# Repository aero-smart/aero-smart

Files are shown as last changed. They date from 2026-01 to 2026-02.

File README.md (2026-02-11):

# AeroSmart — Desktop-Grade Intelligent Wind Tunnel System

## 1. Project Overview

AeroSmart is a desktop-grade intelligent ducted wind tunnel system designed for aeromodeling enthusiasts and early-stage prototype development teams. The project aims to provide a low-cost, repeatable, and engineering-grade validation tool positioned between CFD (Computational Fluid Dynamics) simulations and real flight testing, assisting in the screening and iterative optimization of design schemes.

The system utilizes a modular wind tunnel structure driven by dual ducted fans, capable of generating stable and controllable high-speed airflow within a small-scale test section. It achieves real-time monitoring of wind speed and airflow states through multi-source sensing methods, including Pitot tubes and acoustic sensors. Combined with PID closed-loop control and automated experimental workflows, users can conduct rapid, comparable testing and evaluation of different shapes or structural designs under consistent aerodynamic conditions. Building on this, the system introduces an AI analysis module that provides targeted suggestions for structural or profile improvements based on aerodynamic performance and experimental data, thereby enhancing design iteration efficiency.

* **Precisely Controllable Airflow Output**
* **Natural Language Intelligent Control**
* **Intelligent Optimization and Improvement Prompts**

---

## 2. Target Users and Use Cases

* **Aeromodeling Enthusiasts & Drone Players:** For validating wing and body simulations when large-scale wind tunnels are inaccessible.
    * AeroSmart provides a stable desktop environment for low-cost aerodynamic testing.
    * Controllable wind speeds allow for comparative analysis.
    * Natural Language Control lowers the barrier to entry, requiring no complex wind tunnel or system control experience.

* **Student Startup Projects:** Bridging the gap between CFD simulation and physical prototyping where a low-cost intermediate validation step is missing.
    * Acts as a workflow validation tool for rapid screening of design options.
    * Multi-source sensor data provides a quantitative basis for decisions.
    * AI analysis and optimization tips improve efficiency.

* **Educational Demonstrations:** CFD results can be abstract; real airflow is vital for teaching.
    * Desktop-sized equipment suitable for classroom environments.
    * Real-time visualization and data overlays turn abstract concepts into intuitive phenomena.
    * Adjustable airflow allows for quick demonstrations of different effects and models.

---

## 3. Technical Solution

### 3.1 Technical Specifications

| Module | Purpose | Specification |
| --- | --- | --- |
| **Intake & Filtering** | Generate straight airflow | 5 mm Aluminum Honeycomb + PLA-CF |
| **Contraction Layer (Nozzle)** | Accelerate airflow | 4:1 Area Ratio |
| **Test Section** | Observation & Data | 5" x 3" x 8"; 5 mm PC Panel |
| **Diffuser & Splitter** | Pressure recovery | Y-splitter with 7° expansion angle |
| **Power Source** | Generate airflow | Dual 70mm EDFs, Max 3.6kg/4.6kg thrust |

### 3.2 Hardware Solution

**3.2.1 Structural Materials**
The overall structure primarily uses 3D printing and laser cutting:

* **Intake Filter Section:** 3003 Aluminum Alloy honeycomb for durability; intake frame 3D printed with PLA-CF.
* **Contraction:** Integrated 3D printing using PETG-CF for structural strength.
* **Test Section:** Laser-cut PC panels; TPU (95A) used for gaskets/seals.
* **Diffuser:** PETG-CF, rigid enough to prevent "flutter" or structural vibration during dual EDF operation.
* **Power Mount:** PETG-CF brackets adapted for 3.6 kg thrust levels.
* **External Skeleton:** M5 threaded rods provide axial tension to keep modules compressed and aligned.

**3.2.2 Flow Field Control**

* **Laminar Core:** The contraction design and aluminum honeycomb create a high-quality laminar core in the center of the test section, reducing background disturbance for stable measurements.
* **Shear Simulation:** By applying different RPM commands to EDF1 and EDF2, the internal Y-splitter maintains two distinct velocity zones, creating a controllable shear layer on the model surface to simulate non-uniform wind gradients.
* **Active Gust Modulation:** The STM32H7 performs high-frequency pulse control on the EDFs to simulate atmospheric turbulence and gust loads, testing the structural resonance of models.
* **Angle Control:** An MG90S servo at the bottom of the test section controls the model’s angle of attack (Optional).

### 3.3 Software Solution (Intelligence & Data Architecture)

**3.3.1 Perception Layer**

* **Airspeed Array (MS4525DO, SDP810):** Measures differential pressure to calculate airspeed via Bernoulli’s principle.
* **Omnidirectional Microphone (ICS-43434):** Collects acoustic data to detect potential turbulence and aerodynamic noise.
* **Camera System:** Uses the SolvePnP algorithm and AprilTags for spatial positioning of the object within the test section.
* **IMU (ICM-42688):** Real-time motion and attitude data collection.
* **Pressure Sensors:** Monitors real-time forces acting on the experimental object.

**3.3.2 Processing Layer**

* **STM32H7:** Handles real-time PID control for thrust stability and Fast Fourier Transform (FFT) on microphone data for acoustic profiling.
* **Raspberry Pi (or Orange Pi):** Runs the MCP Server as an interface for Large Language Models (LLM), enabling natural language queries of sensor data and wind condition commands. It will also host small machine learning models for experimental data analysis.

**3.3.3 Visualization Layer**

* Real-time telemetry displayed via a **Web Dashboard**.
* **"Aero-Current" vectors** overlaid on real-time video of the model.
* **Smoke generator** for immediate visual observation of flow states.

---

## 4. Project Roadmap

| Phase | Core Tasks | Key Deliverables |
| --- | --- | --- |
| **Phase 1: Fluid Prototype** | Printing, honeycomb assembly, single EDF testing. | Stable laminar output (Smoke test). |
| **Phase 2: Perception Fusion** | Integrate Pitot, MIC, IMU, and STM32 PID control. | Real-time airspeed & attitude dashboard. |
| **Phase 3: Smart Interaction** | Raspberry Pi & MCP Server; LLM interface. | Voice/Text control of wind tunnel. |
| **Phase 4: AI Analysis** | Data accumulation; regression model training. | Automated experimental evaluation reports. |

*Target for the current term: Achieve at least Phase 2 and partially complete Phase 3.*

---

## 5. Development and Deployment

### 5.1 Repository Structure

```
aero-smart/
├── firmware/           # STM32H7 embedded Rust firmware (Embassy async runtime)
├── service/            # Backend service (Axum web framework, GraphQL, PostgreSQL)
├── shared/             # Shared Rust library (no_std compatible, cross-platform types)
├── panel/              # Vue.js 3 + Tauri desktop application
├── schematics/         # Electronic circuit schematics
├── model/              # CAD models (STEP format)
└── .github/workflows/  # CI/CD pipelines
```

### 5.2 CI/CD Pipeline

The repository includes automated CI/CD workflows:

#### Build Pipeline for OrangePi Zero 3 (aarch64)

**Workflow:** `.github/workflows/build-aarch64.yml`

This workflow automatically builds the Tauri desktop application for OrangePi Zero 3 (Cortex-A53, aarch64 architecture) with a 1024x600 display when:
- Code is pushed to the `main` branch (panel or shared components)
- Pull requests are created that modify panel or shared code
- Manually triggered via workflow dispatch

**Features:**
- Cross-compilation for aarch64-unknown-linux-gnu target
- Builds .deb packages for easy installation on Debian-based systems
- Artifacts are automatically uploaded and retained for 30 days
- Optimized for OrangePi Zero 3 with fullscreen 1024x600 display

**Build artifacts include:**
- Debian package (.deb) for easy installation
- Build information with commit details and target platform

#### Continuous Integration Pipeline

**Workflow:** `.github/workflows/ci.yml`

Automatically runs checks on code changes:
- Detects which components changed (firmware, service, panel, shared)
- Runs targeted CI tasks for affected components only
- Performs linting, type checking, and builds

### 5.3 Building for OrangePi Zero 3

The panel application is optimized for OrangePi Zero 3 with specific configurations:

**Display Settings:**
- Resolution: 1024x600
- Fullscreen mode enabled
- Window decorations disabled
- Always on top for embedded use

**Build Options:**

1. **Using GitHub Actions (Recommended):**
   - Simply push your code to trigger automatic builds
   - Download artifacts from the Actions tab

2. **Local Build with Docker:**
   ```sh
   ./build_aarch64.sh
   ```

3. **Local Build with npm:**
   ```sh
   cd panel
   pnpm install
   pnpm tauri:build:aarch64
   ```

4. **Using just:**
   ```sh
   just build-panel-aarch64
   ```

For detailed cross-compilation setup instructions, see [panel/README.md](panel/README.md).

### 5.4 Development Workflow

1. **Firmware Development:**
   ```sh
   just build-firmware
   cd firmware && cargo run --release  # Flash to STM32
   ```

2. **Service Development:**
   ```sh
   cargo run -p aerosmart-service
   ```

3. **Panel Development:**
   ```sh
   cd panel
   pnpm install
   pnpm tauri:dev  # Development mode with hot-reload
   ```

For more details, see [CLAUDE.md](CLAUDE.md) for comprehensive development documentation.

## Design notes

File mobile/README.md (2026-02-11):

# mobile

Next Generation Aerodynamic Analysis

## Getting Started

This project is a starting point for a Flutter application.

A few resources to get you started if this is your first Flutter project:

- [Lab: Write your first Flutter app](https://docs.flutter.dev/get-started/codelab)
- [Cookbook: Useful Flutter samples](https://docs.flutter.dev/cookbook)

For help getting started with Flutter development, view the
[online documentation](https://docs.flutter.dev/), which offers tutorials,
samples, guidance on mobile development, and a full API reference.

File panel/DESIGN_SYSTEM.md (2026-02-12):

# AeroSmart Design System

## 1. Introduction

This document outlines the design system for the AeroSmart control panel. The system is built on Tailwind CSS and provides a consistent set of tokens, components, and layout rules to ensure a unified user experience.

## 2. Design Tokens

### Colors

The color palette is semantic and supports theming via CSS variables.

| Token | Variable | Description |
| --- | --- | --- |
| `primary` | `--color-primary` | Main action color (Black) |
| `secondary` | `--color-secondary` | Secondary backgrounds (Light Gray) |
| `accent` | `--color-accent` | Highlight color (Blue) |
| `success` | `--color-success` | Success state (Green) |
| `warning` | `--color-warning` | Warning state (Yellow) |
| `danger` | `--color-danger` | Error/Destructive state (Red) |

### Backgrounds

| Token | Variable | Description |
| --- | --- | --- |
| `bg-page` | `--bg-page` | Main application background |
| `bg-surface` | `--bg-surface` | Card/Panel background |
| `bg-sidebar` | `--bg-sidebar` | Sidebar background |

### Typography

We use the system font stack with Inter as the preferred font.

- **Font Family**: Inter, -apple-system, BlinkMacSystemFont, ...
- **Weights**: Regular (400), Medium (500), Semibold (600), Bold (700)

### Spacing

Based on an 4px grid system.

- `p-1` = 4px
- `p-2` = 8px
- `p-4` = 16px
- `p-6` = 24px

## 3. Components

### Button (`@/components/ui/Button.vue`)

Standard button component with variants.

```vue
<Button variant="primary">Primary Action</Button>
<Button variant="outline">Secondary Action</Button>
<Button variant="ghost" size="icon"><Icon /></Button>
```

### Card (`@/components/ui/Card.vue`)

Content container with consistent styling.

```vue
<Card title="Card Title">
  <p>Content goes here...</p>
</Card>
```

### Badge (`@/components/ui/Badge.vue`)

Status indicator.

```vue
<Badge variant="success" dot>Online</Badge>
```

### Input (`@/components/ui/Input.vue`)

Standard text input.

```vue
<Input v-model="value" label="Username" placeholder="Enter username" />
```

## 4. Layout

### PageLayout (`@/components/layout/PageLayout.vue`)

Standard page structure with header and scrollable content area.

```vue
<PageLayout title="Dashboard">
  <template #actions>
    <Button>Action</Button>
  </template>
  <!-- Content -->
</PageLayout>
```

### Container (`@/components/layout/Container.vue`)

Centers content with max-width and padding.

### Grid (`@/components/layout/Grid.vue`)

Responsive grid layout wrapper.

```vue
<Grid :cols="3">
  <Card>...</Card>
  <Card>...</Card>
  <Card>...</Card>
</Grid>
```

## 5. Iconography

We use **Lucide Vue Next** for icons.

- **Style**: Line style, 2px stroke width.
- **Size**: Default to `16px` (sm), `20px` (md), `24px` (lg).
- **Color**: Use `text-gray-400` for inactive/neutral icons, `text-primary` for active.

## 6. Guidelines

1.  **Use Semantic Colors**: Avoid hardcoded hex values (e.g., use `text-primary` instead of `#1f2937`).
2.  **Use Spacing Scale**: Use Tailwind classes (`p-4`, `m-2`) instead of arbitrary pixels.
3.  **Consistent Cards**: Wrap distinct content sections in `Card` components.
4.  **Responsive First**: Build mobile-first layouts using standard breakpoints (`md`, `lg`).

## 6. Accessibility

- Ensure sufficient color contrast for text.
- Use semantic HTML elements.
- Provide aria-labels for icon-only buttons.

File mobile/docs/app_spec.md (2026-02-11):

# AeroSmart Mobile App Specification

## 1. Overview
This document outlines the specifications for the AeroSmart mobile application, built with Flutter. The app serves as a control and monitoring interface for the AeroSmart wind tunnel system.

**Design Philosophy:**
- **Style:** Minimalist Material Design (Black & White).
- **Focus:** Clarity, performance, and professional engineering aesthetics.

## 2. Core Features

### 2.1 Configuration Management
- Modify all system configuration parameters.
- Real-time adjustment of control parameters (e.g., PID coefficients, if exposed).
- Control actuators:
    - **Throttle:** Dual EDF thrust control (0-100%).
    - **Servo:** Angle of attack adjustment.
- System Commands: Start, Stop, Calibrate, Emergency Stop.

### 2.2 Firmware Update
- Over-the-air (OTA) or wired firmware updates for the STM32H7 microcontroller.
- Progress tracking and verification.

### 2.3 Data Monitoring
- Real-time telemetry visualization.
- **Sensors:**
    - **Airspeed:** Differential pressure & calculated velocity.
    - **IMU:** Acceleration, Gyroscope, Quaternion (Attitude).
    - **Environmental:** Pressure, Temperature, Humidity.
    - **Lidar:** Distance measurements.
    - **Battery:** Voltage and State of Charge (SoC).
    - **Acoustic:** FFT spectrum data (future).

### 2.4 3D Attitude Indicator
- Real-time 3D visualization of the wind tunnel model's orientation based on IMU quaternion data.
- Interactive 3D model viewer.

## 3. Page Structure

### 3.1 Dashboard (Home)
The main landing page providing an immediate system status overview.
- **Header:** Connection status (Bluetooth/WiFi), Battery level.
- **Primary Metrics:** Current Airspeed, Throttle %, Active Mode.
- **3D Widget:** A small, live 3D representation of the model's attitude.
- **Quick Actions:** Emergency Stop, Start/Stop Toggle.

### 3.2 Data Monitor
Detailed view of all sensor streams.
- **Tabbed/Scrollable View:**
    - **Flight Dynamics:** IMU data graphs (Accel/Gyro), Euler angles.
    - **Aerodynamics:** Airspeed, Pitot pressure graphs.
    - **Environment:** Barometer, Lidar distance.
- **Features:** Data logging toggle (future), graph time-scale adjustment.

### 3.3 Controls & Settings
Comprehensive control panel for system parameters.
- **Actuator Control:** Sliders/Inputs for Throttle and Servo Angle.
- **System Config:**
    - PID Tuning parameters (P, I, D for Airspeed/Attitude).
    - Sensor Calibration triggers.
    - Safety limits configuration (Max Throttle, Max Angle).

### 3.4 Firmware
Dedicated page for system maintenance.
- **Current Version:** Display running firmware version.
- **Update:** File picker or cloud fetch for new firmware binaries.
- **Process:** Flash button with progress bar and status log.

## 4. Technical Architecture

### 4.1 Tech Stack
- **Framework:** Flutter (Dart)
- **UI Library:** Material Design 3
- **State Management:** Riverpod
- **Routing:** GoRouter
- **3D Rendering:** `flutter_3d_controller` or `model_viewer_plus`

### 4.2 Project Structure
```
lib/
├── main.dart           # Entry point
├── core/               # Core utilities, theme, constants
│   ├── theme/          # AppTheme (Black & White)
│   └── router/         # GoRouter configuration
├── features/
│   ├── dashboard/      # Dashboard page & widgets
│   ├── monitor/        # Data monitoring page
│   ├── controls/       # Control panel
│   ├── firmware/       # Firmware update logic
│   └── settings/       # App settings
├── shared/             # Shared widgets & models
│   ├── models/         # Data models (ImuData, Config, etc.)
│   └── widgets/        # Reusable UI components
└── services/           # Communication services (Bluetooth/Http - Placeholders for now)
```

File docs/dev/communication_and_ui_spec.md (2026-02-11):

# AeroSmart 上下位机通信协议与前端页面规划文档

本文档详细描述了 AeroSmart 系统中上位机（Panel/Service）与下位机（Firmware）之间的通信协议，WebSocket 接口细节，以及前端各页面的功能期待。

## 1. 通信架构概览

系统采用如下通信链路：
`Firmware (STM32)` <==[Serial (UART)]==> `Service (Tauri Background Task)` <==[WebSocket (JSON)]==> `Frontend (Vue 3)`

*   **下位机 <-> Service**: 使用基于 `rkyv` 的零拷贝二进制协议，为了保证传输稳定，采用了 **Length-Prefixed (4字节长度前缀)** 的分包机制。
*   **Service <-> 前端**: 使用标准 WebSocket 协议，数据格式为 JSON。Service 负责将二进制数据转译为 JSON 广播给前端，并将前端的 JSON 指令转译为二进制发送给下位机。

## 2. 握手协议 (Handshake)

在正式通信前，下位机与 Service 必须完成一次握手以同步状态和时间。

1.  **Service 启动**: 打开串口，进入等待状态。
2.  **下位机发送 Ping**: 发送 `AcknowledgementData` 消息。
3.  **Service 回复 Pong**: 收到合法 Ping 后，Service 获取当前 Unix 时间戳，封装在 `AcknowledgementConfig` 消息中回复。
4.  **连接建立**: 双方进入主循环，开始全双工数据传输。

## 3. WebSocket 接口文档

*   **Endpoint**: `ws://localhost:3000/ws`
*   **数据格式**: JSON
*   **序列化规则**: 遵循 Rust `serde` 的 Enum 外部标签格式，即 `{ "VariantName": { ...fields... } }`。

### 3.1 下行链路 (Downlink): 遥测数据
Service 会将收到的串口数据广播给所有连接的 WebSocket 客户端。

#### 1. IMU 姿态数据 (`ImuData`)
频率: ~20Hz
```json
{
  "ImuData": {
    "accel_z": 9.81,
    "gyro_x": 0.01,
    "gyro_y": -0.02,
    "quad_w": 1.0,
    "quad_i": 0.0,
    "quad_j": 0.0,
    "quad_k": 0.0,
    "time_elapsed_ms": 123456
  }
}
```
*   前端用途: 更新 3D 姿态球或飞机模型。

#### 2. 空速数据 (`PitotAirspeedData`)
频率: ~10Hz
```json
{
  "PitotAirspeedData": {
    "splitter_left": 12.5,
    "splitter_right": 13.0,
    "static_port": 101325.0,
    "time_elapsed_ms": 123456
  }
}
```
*   前端用途: 显示实时空速 (m/s 或 km/h)。

#### 3. 电池状态 (`BatteryData`)
频率: ~1Hz
```json
{
  "BatteryData": {
    "voltage_v": 12.4,
    "soc_percent": 85.0,
    "time_elapsed_ms": 123456
  }
}
```
*   前端用途: 顶部状态栏显示电量和电压图标。

#### 4. 激光雷达测距 (`LidarData`)
频率: ~5Hz
```json
{
  "LidarData": {
    "distance_cm": 150,
    "signal_strength": 100,
    "time_elapsed_ms": 123456
  }
}
```
*   前端用途: 显示对地高度或避障距离。

#### 5. 环境数据 (`BarometerData`)
频率: ~1Hz
```json
{
  "BarometerData": {
    "pressure_pa": 101300.0,
    "temperature_c": 25.5,
    "humidity_percent": 45.0,
    "time_elapsed_ms": 123456
  }
}
```
*   前端用途: 显示环境仪表盘。

#### 6. 声学特征 (`AcousticData`)
频率: ~20Hz
```json
{
  "AcousticData": {
    "overall_spl": 80.5,
    "peak_frequency": 1200.0,
    "peak_magnitude": 0.8,
    "spectral_shape": [0.1, 0.2, ...], // 16 bins
    "turbulence_index": 0.45,
    "time_elapsed_ms": 123456
  }
}
```
*   前端用途: 绘制实时频谱图 (Spectrum Analyzer) 和噪声等级仪表。

#### 7. 振动监测 (`ImuVibrationMetrics`)
频率: ~1Hz
```json
{
  "ImuVibrationMetrics": {
    "accel_z": { "rms_vibration": 0.5, "dominant_frequency_hz": 50.0, "peak_magnitude": 1.2, "time_elapsed_ms": ... },
    "gyro_x": { ... },
    "gyro_y": { ... }
  }
}
```
*   前端用途: 显示机身震动健康度。

### 3.2 上行链路 (Uplink): 控制指令
前端通过 WebSocket 发送 JSON 字符串控制设备。

#### 1. 设置油门/空速 (`ThrottleConfig`)
```json
{
  "ThrottleConfig": {
    "airspeed": 128 // 0-255 映射到 PWM 或 目标速度
  }
}
```

#### 2. 设置舵机角度 (`ServoConfig`)
```json
{
  "ServoConfig": {
    "angle": 90 // 0-180 度
  }
}
```

#### 3. 系统命令 (`Command`)
*   **启动**:
    ```json
    { "Command": "Start" }
    ```
*   **停止**:
    ```json
    { "Command": "Stop" }
    ```
*   **校准**:
    ```json
    { "Command": "Calibrate" }
    ```

#### 4. 传感器配置 (`SensorConfig`)
```json
{
  "SensorConfig": {
    "imu_horizontal": true
  }
}
```

---

## 4. 前端页面功能规划与期待

基于上述数据流，前端应用 (`panel`) 的各页面应包含以下核心功能模块：

### 4.1 仪表盘 (Dashboard)
**定位**: 全局状态监视，核心飞行数据的实时展示。

*   **飞行姿态仪 (PFD)**:
    *   利用 `ImuData` (Quaternions) 渲染 3D 姿态球 (Artificial Horizon)。
    *   显示俯仰角 (Pitch) 和滚转角 (Roll)。
*   **核心指标栏**:
    *   **空速**: 仪表盘样式展示 `PitotAirspeedData`。
    *   **高度/距离**: 数字展示 `LidarData`。
    *   **环境**: 小卡片展示 `BarometerData` (温湿度、气压)。
*   **声学频谱分析**:
    *   使用 ECharts 或 Canvas 绘制 `AcousticData.spectral_shape` 的实时柱状图或折线图。
    *   显示当前 SPL (分贝) 和湍流指数。

### 4.2 控制台 (Control)
**定位**: 主动控制飞机的执行机构和运行状态。

*   **系统状态控制**:
    *   大尺寸按钮组: [启动 (Start)] [停止 (Stop)] [传感器校准 (Calibrate)]。
    *   状态指示灯: 对应下位机反馈的状态（需下位机配合回传状态，目前可通过心跳或特定回传判断）。
*   **油门推杆**:
    *   垂直滑块 (Slider) 控制 `ThrottleConfig`。
    *   实时显示当前设定值 (0-100%)。
*   **舵机测试**:
    *   旋钮或水平滑块控制 `ServoConfig` (0-180°)。
    *   提供“归中 (90°)”快捷按钮。
*   **旋钮编码器反馈**:
    *   显示 `QeiData` 的计数和按键状态，可用于验证物理旋钮输入。

### 4.3 设置 (Settings)
**定位**: 系统级配置与调试信息。

*   **连接配置**:
    *   显示当前连接的串口号、波特率（从 Service 状态获取，或仅做静态展示）。
    *   WebSocket 连接状态指示 (Connected/Disconnected)。
*   **传感器配置**:
    *   开关组件 (Switch) 控制 `SensorConfig.imu_horizontal` (水平/垂直安装校正)。
*   **原始数据监控 (Debug Console)**:
    *   滚动文本框显示收到的原始 JSON 消息流，方便开发调试。
    *   提供“暂停滚动”和“清屏”功能。
*   **阈值报警设置** (前端逻辑):
    *   设置电压低报警阈值。
    *   设置过载 (G-force) 报警阈值。

### 4.4 全局布局 (Layout)
*   **顶部栏 (Status Bar)**:
    *   始终显示: WebSocket 连接状态图标。
    *   始终显示: `BatteryData` (电压/电量)。
    *   始终显示: 系统时间。
*   **侧边栏 (Sidebar)**:
    *   导航菜单: Dashboard / Control / Settings。

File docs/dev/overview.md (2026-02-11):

## AeroSmart — System Overview

AeroSmart is a **desktop-scale intelligent ducted wind tunnel** for aerodynamic testing. It generates controlled airflow (up to 24 m/s) through a 125×75 mm test section using dual 70mm electric ducted fans (EDFs), measures aerodynamic forces via a suite of sensors, and presents real-time data through a web dashboard. The system targets aeromodeling enthusiasts, student engineering teams, and educational demonstrations.

The monorepo contains four major components plus hardware design files:

```
┌──────────────┐    UART/rkyv     ┌──────────────┐   GraphQL/JSON   ┌──────────────┐
│   FIRMWARE   │ ◄──────────────► │   SERVICE    │ ◄──────────────► │    PANEL     │
│  (STM32H7)   │   915200 baud    │  (Axum/PG)   │    HTTP/WS       │  (Vue 3/TS)  │
│ Embassy Rust │                  │  Rust Tokio  │                  │  Vite + Pinia│
└──────────────┘                  └──────────────┘                  └──────────────┘
       │                                │
       │ SPI/I2C/UART/PWM               │ SQLx
       ▼                                ▼
  ┌──────────┐                   ┌──────────────┐
  │ SENSORS  │                   │ PostgreSQL   │
  │ ACTUATORS│                   │  + pgvector  │
  └──────────┘                   └──────────────┘
```

The **shared** crate (`aerosmart-shared`) sits between firmware and service, providing `no_std`-compatible type definitions for all messages and database records.

------

## 1. Firmware (`firmware/`) — Embedded Real-Time Control

The firmware runs on an **STM32H743VG** (ARM Cortex-M7 @ 400 MHz) using the **Embassy async runtime** — a cooperative, interrupt-driven executor purpose-built for embedded Rust.

### 1.1 Initialization (`main.rs`)

On boot, the firmware:

1. **Configures clocks**: PLL1_P → 400 MHz core, 200 MHz AHB, 100 MHz APB
2. **Initializes peripherals**:
   - **SPI1** @ 1 MHz → ICM-42688-P IMU
   - **I2C1** @ 400 kHz → MS4525DO pitot tube + BME280 barometer
   - **I2C3** @ 400 kHz → ADS1115 ADC (analog pressure sensors)
   - **USART1** @ 915200 baud → backend serial link
   - **USART3** @ 115200 baud → TF-Mini S LIDAR
   - **TIM1** @ 600 kHz → DShot ESC protocol for dual EDFs
   - **TIM2** @ 50 Hz → MG90S servo PWM
   - **TIM3** → Quadrature encoder input (QEI)
   - **SPI2** → WS2812B addressable LEDs
   - **SAI1** → I2S stereo microphone @ 44.1 kHz
   - **IWDG** → Independent watchdog (20s timeout)
3. **Spawns concurrent tasks** based on compile-time feature flags (e.g., `airspeed-control`, `fft`, `ahrs`, `imu`, `lidar`, `serial`)

A `TestConfig` struct controls which subsystems are active, allowing selective hardware testing.

### 1.2 Global State (`state.rs`)

All tasks share a single `GlobalState` struct protected by `Mutex<CriticalSectionRawMutex, _>`. It holds:

- **Machine status**: `Idle | Initializing | Running | Error | EmergencyStop`
- **Control mode**: `Manual | Assisted | Autonomous`
- **Sensor readings**: current airspeed, IMU samples, barometer data, battery voltage/SOC, LIDAR distance, analog pressure channels, quaternion attitude, vibration metrics, acoustic FFT data
- **IMU circular buffers**: 1024-sample ring buffers for `accel_z`, `gyro_x`, `gyro_y` (used by FFT task)
- **Setpoints**: desired airspeed, desired servo angle
- **Environmental**: air density (updated from barometer)

Inter-task communication uses **Embassy Signals** (wake-based, single-value) and **Channels** (buffered MPSC queues):

| Signal | Producer | Consumer | Purpose |
| :--- | :--- | :--- | :--- |
| `AIRSPEED_UPDATED_SIGNAL` | Airspeed task | EDF task | Triggers PID recalculation  |
| `IMU_UPDATED_SIGNAL` | IMU task | Serial TX  | New attitude data available |
| `IMU_BUFFER_FULL_SIGNAL`  | IMU task | FFT task | 1024 samples collected |
| `STATUS_UPDATED_SIGNAL` | Various | LED task | Machine state changed |
| `DESIRED_UPDATE_SIGNAL` | Serial RX | Servo task | New angle setpoint |

### 1.3 Sensor Drivers

Each sensor has a low-level driver (register definitions) and a high-level interface:

**ICM-42688-P IMU** (`sensors/imu_spi.rs`, `drivers/icm_42688_p.rs`):

- 6-DOF: ±16g accelerometer + ±2000 dps gyroscope
- SPI register access with configurable full-scale range and output data rate
- Event-driven at ~1 kHz via GPIO interrupt (data-ready pin)

**MS4525DO Pitot Tube** (`sensors/pitot_i2c.rs`):

- Differential pressure sensor at I2C address 0x28
- 14-bit raw pressure → ±1 PSI (±6894 Pa)
- 11-bit temperature: `(raw × 200/2047) − 50`
- Polled at 100 Hz
- Kalman filter implemented

**BME280 Barometer** (`drivers/bme_280.rs`):

- Pressure, temperature, humidity at I2C address 0x76
- 4× oversampling, normal mode
- Polled at 10 Hz (decimated from the 100 Hz pitot loop)
- Used to compute real-time air density via the Magnus formula

**ADS1115 ADC** (`sensors/adc_i2c.rs`, `drivers/ads1115.rs`):

- 16-bit, 4-channel ADC at I2C address 0x48
- Reads analog pressure transducers (XGZP6847A) and battery voltage
- Single-shot conversion triggered with data-ready interrupt

**TF-Mini S LIDAR** (`sensors/lidar_uart.rs`):

- 9-byte UART frames (header `0x59 0x59`, distance_cm, signal_strength)
- Polled every 3 seconds
- **Safety**: triggers `EmergencyStop` if distance < 30 cm

**ICS-43434 Microphone** (`audio_i2s.rs`):

- I2S stereo, 24-bit, 44.1 kHz via SAI1
- 4096-sample buffer for acoustic FFT

### 1.4 Algorithms

**PID Airspeed Controller** (`algorithms/airspeed.rs`):

The controller uses a **feedforward + feedback** architecture with three operating states:

| State | Condition | Strategy |
| :--- | :--- | :--- |
| **Reaching** | error > 20% | Pure feedforward from mass conservation model |
| **Approaching** | 5% < error ≤ 20% | Sigmoid-weighted blend of feedforward + PID |
| **Cruising** | error ≤ 5% | Full PID feedback control |

The feedforward model derives throttle from physics:
$$
v_{\mathrm{edf}} = \sqrt{\dfrac{F_\mathrm{thrust}}{\rho \cdot A_{\mathrm{edf}}}}\\
\mathrm{throttle} = \dfrac{v_{\mathrm{desired}}}{v_\max}
$$
Voltage compensation scales for battery sag. PID gains: $K_p=1.0, K_i=0.1, K_d=0.05$, output clamped to ±50.

**Madgwick AHRS** (`algorithms/madgwick.rs`):

- Fuses accelerometer + gyroscope into a quaternion ($w, i, j, k$)
- Sample rate: 1000 Hz, beta: 0.033
- Outputs Euler angles (roll, pitch, yaw) for telemetry

**Kalman Airspeed Filter** (`algorithms/airspeed_filter.rs`):

- Single-state Kalman filter for smoothing pitot readings
- Process variance $Q=0.001$, measurement variance R=0.1

**Motion FFT** (`algorithms/motion_fft.rs`):

- 1024-point real FFT on IMU circular buffer using `microfft`
- Hann windowing (generated at compile time by `build.rs`)
- Extracts: RMS vibration, dominant frequency, peak magnitude

**Acoustic FFT** (`algorithms/acoustic_fft.rs`):

- 4096-point real FFT on microphone data
- Blackman-Harris windowing (better sidelobe suppression)
- Extracts: overall SPL, peak frequency, 16-band spectral shape, turbulence index (spectral flux)

### 1.5 Concurrent Tasks

All tasks run as Embassy async functions on the Cortex-M7:

| Task | Rate | Key Logic |
| :--- | :--- | :--- |
| **Airspeed** | 100 Hz | Reads pitot, computes airspeed from Bernoulli `v=√(2ΔP/ρ)`, updates state |
| **IMU** | 1 kHz | Reads IMU via SPI, runs Madgwick AHRS, fills FFT buffer |
| **EDF** | event-driven | Waits for `AIRSPEED_UPDATED_SIGNAL`, runs PID, sends DShot to both EDFs |
| **Servo** | event-driven | Waits for `DESIRED_UPDATE_SIGNAL`, sets PWM duty cycle |
| **IMU FFT** | event-driven | Waits for `IMU_BUFFER_FULL_SIGNAL`, computes vibration metrics |
| **LIDAR** | 0.33 Hz | Measures distance, triggers emergency stop on proximity |
| **Battery** | 1 Hz | Reads ADC, computes voltage and SOC from lookup table |
| **Analog Pressure** | 20 Hz | Polls ADS1115 across 4 channels |
| **LED** | event-driven | Maps machine status to WS2812B color |
| **Watchdog** | 1 Hz | Pets the independent watchdog |
| **Acoustic Sample** | continuous | Streams I2S audio, buffers 4096 samples |
| **Acoustic Analysis** | event-driven | FFT on audio, extracts spectral features |
| **Serial RX** | continuous | Deserializes rkyv commands from service |
| **Serial TX** | 100 Hz base  | Transmits telemetry at tiered rates (IMU@20Hz, airspeed@10Hz, LIDAR@5Hz, battery@1Hz) |
| **QEI** | 20 Hz | Reads encoder position and button state |

### 1.6 Actuator Control

**Dual EDFs** (`executors/edf.rs`): Controlled via DShot digital protocol over TIM1 PWM at 600 kHz. Throttle range 0–2000. Both fans receive symmetric commands.

**Servo** (`executors/servo.rs`): Standard 50 Hz PWM on TIM2. Pulse width maps linearly: 1.0 ms (0°) to 2.0 ms (180°).

### 1.7 Utility Modules

- **`utils/pitot.rs`**: Bernoulli equation $v=\sqrt{\dfrac{2\cdot\Delta P}{\rho}}$
- **`utils/mass_conservation.rs`**: Feedforward throttle from thrust equation and continuity
- **`utils/magnus.rs`**: Moist air density from Magnus saturation vapor pressure formula
- **`utils/battery.rs`**: VREFINT-calibrated ADC conversion, 21-point SOC lookup table for 4S LiPo
- **`utils/pressure_adc.rs`**: Analog pressure transducer voltage-to-Pa conversion

------

## 2. Shared Library (`shared/`) — Cross-Platform Types

The `aerosmart-shared` crate is `#![no_std]`-compatible with feature gates:

| Feature | What it enables |
| :--- | :--- |
| `std` (default) | Standard library, rkyv std, chrono std |
| `sql` | SQLx `FromRow`, pgvector, UUID types |
| `serde` | JSON serialization for web API |
| `defmt` | Embedded logging format |
| `graphql` | Juniper GraphQL derives |
| `proto` | Protobuf via prost |

### 2.1 Serial Protocol (`serial.rs`)

Defines all messages exchanged over UART:

**Service → Firmware (Commands)**:

- `ThrottleConfig { airspeed: u8 }` — target airspeed percentage
- `ServoConfig { angle: u8 }` — angle of attack
- `SensorConfig { imu_horizontal: bool }` — IMU orientation
- `Command { Start | Stop | Calibrate }` — state machine control
- `AcknowledgementConfig { ack: bool, unix_timestamp_ms: u64 }`

**Firmware → Service (Telemetry)**:

- `ImuData` — accel_z, gyro_x/y, quaternion (w/i/j/k), timestamp
- `PitotAirspeedData` — splitter_left/right, static_port, timestamp
- `AcousticData` — SPL, peak_frequency, peak_magnitude, 16-band spectral_shape, turbulence_index
- `ImuVibrationMetrics` — RMS, dominant_frequency, peak_magnitude (×3 axes)
- `BarometerData` — pressure, temperature, humidity
- `BatteryData` — voltage, SOC percentage
- `LidarData` — distance_cm, signal_strength
- `AnalogPressureSensorData` — 4 channels + validity bitmask
- `QeiData` — encoder position, direction, button state

All types are wrapped in a `SerialMessage` enum. Serialized with **rkyv** for zero-copy decoding — the firmware can interpret messages in-place without allocation.

### 2.2 Database Records (`sql.rs`)

Conversion methods (`to_record(session_uuid)`) transform telemetry structs into SQL-ready records:

- `ImuRecord` — includes full quaternion, references experiment session UUID
- `PitotAirspeedRecord` — three pressure channels per session
- `AcousticRecord` — SPL + spectral_shape stored as `pgvector::Vector` for ML similarity queries
- `Experiment` — session metadata (name, description, UUID)

------

## 3. Backend Service (`service/`) — Web API & Persistence

The service is built on **Axum** (web framework), **Juniper** (GraphQL), **SQLx** (PostgreSQL), and **tokio-serial** (UART).

**Current status**: The service is in **skeleton phase** — dependencies are configured, the database migration is written, and the serial wrapper exists, but the Axum server, GraphQL schema, and database query layer are not yet implemented.

### 3.1 Database Schema (`migrations/20260111031124_initial.sql`)

```sql
-- Extensions
CREATE EXTENSION IF NOT EXISTS vector;       -- pgvector for embeddings
CREATE EXTENSION IF NOT EXISTS "uuid-ossp";  -- UUID generation

-- Tables
experiments         (id UUID PK, name, description, created_at, updated_at)
imu_records         (id SERIAL PK, session FK, timestamp, accel/gyro/quaternion fields)
pitot_airspeed_records (id SERIAL PK, session FK, timestamp, 3 pressure channels)
acoustic_records    (id SERIAL PK, session FK, timestamp, SPL, peak_freq,
                     spectral_shape vector(32), turbulence_index)
```

Indexes cover session+timestamp lookups (descending) and an HNSW vector cosine similarity index on `acoustic_records.spectral_shape` for nearest-neighbor queries.

### 3.2 Serial Communication (`serial/mod.rs`)

A thin wrapper around `tokio_serial::SerialPort` with raw `read()`/`write()` methods. The intended flow:

1. Service opens UART port at 915200 baud
2. Incoming bytes are deserialized via rkyv into `SerialMessage` variants
3. Telemetry data is persisted to PostgreSQL and broadcast to frontend
4. Commands from frontend are serialized and sent to firmware

### 3.3 Planned Architecture

Based on dependencies and the shared library:

- **Axum routes**: REST + GraphQL endpoint (`/graphql`)
- **Juniper resolvers**: queries for experiments, sensor data; mutations for experiment management and control commands
- **SQLx pool**: connection pooling with type-safe queries
- **Context/DI**: `AppState` holding DB pool, serial handle, and schema

------

## 4. Frontend Panel (`panel/`) — Vue 3 Dashboard

A **Vue 3 + TypeScript + Vite** application using Pinia for state management.

**Current status**: Clean boilerplate — the toolchain is fully configured but no application features are implemented yet.

### 4.1 Toolchain

| Tool | Version | Purpose |
| :--- | :--- | :--- |
| Vite | 8.0.0-beta.7 | Build tool + HMR dev server |
| Vue | 3.5.26 | UI framework (Composition API) |
| Pinia | 3.0.4 | State management |
| Vue Router | 4.6.4 | Client-side routing |
| TypeScript | 5.9.3 | Type safety |
| vue-tsc | 3.2.2 | Vue template type checking |
| Vitest | 4.0.16 | Unit testing |
| Playwright | 1.57.0 | E2E testing (Chromium, Firefox, WebKit) |
| ESLint + Oxlint | 9.39.2 / 1.38.0 | Linting |
| Prettier | 3.7.4 | Formatting (no semicolons, single quotes) |

### 4.2 Application Bootstrap

```
index.html → src/main.ts → createApp(App)
  → app.use(createPinia())    // State management
  → app.use(router)           // Routing
  → app.mount('#app')         // DOM mount
```

The router has no routes defined yet. A single example Pinia store (`counter.ts`) demonstrates the Composition API pattern.

------

## 5. End-to-End Data Flow

Here's how a complete airspeed control loop works:

```
1. USER sets target airspeed in Vue dashboard
2. PANEL sends GraphQL mutation to SERVICE
3. SERVICE serializes ThrottleConfig via rkyv, writes to UART
4. FIRMWARE Serial RX task deserializes command, updates desired_airspeed in GlobalState
5. FIRMWARE Airspeed task reads MS4525DO pitot tube at 100 Hz
   → Bernoulli: v = √(2ΔP/ρ)
   → ρ updated from BME280 every 10 cycles
   → Kalman filter smooths measurement
   → Fires AIRSPEED_UPDATED_SIGNAL
6. FIRMWARE EDF task wakes, reads current vs desired airspeed
   → PID controller computes throttle (feedforward + feedback)
   → Sends DShot command to both EDFs via TIM1
7. FIRMWARE Serial TX sends PitotAirspeedData @ 10 Hz over UART
8. SERVICE deserializes telemetry, stores in PostgreSQL, pushes to frontend
9. PANEL updates dashboard in real-time
```

Safety runs in parallel:

- Watchdog task pets IWDG every 1s (20s timeout → hardware reset on hang)
- LIDAR checks proximity every 3s → `EmergencyStop` if < 30 cm
- Battery task monitors voltage → warnings on low SOC

------

## 6. Build System

**Firmware**: Rust 1.90, target `thumbv7em-none-eabi`, flashed via `probe-rs`. The `build.rs` generates FFT window coefficients (Hann 1024-point, Blackman-Harris 1024-point) at compile time. Both dev and release profiles use LTO and size optimization (`opt-level = "z"`).

**Service**: Standard Rust with Tokio async runtime. Database migrations via SQLx.

**Frontend**: pnpm + Vite. `pnpm build` runs `vue-tsc --build` (type check) then Vite production build in parallel.

**Workspace**: Cargo workspace with resolver v2, three members (`firmware`, `service`, `shared`). Panel is outside the Cargo workspace (Node.js project).

------

## 7. Project Status

The project is in **Phase 2 (Perception Fusion)**:

| Component | Status |
| :--- | :--- |
| Firmware | **Substantially complete** — all sensor drivers, algorithms, tasks, and actuator control are implemented |
| Shared library  | **Complete** — all message types, database records, and serialization are defined with tests |
| Backend service | **Skeleton** — dependencies configured, migration written, serial wrapper exists, but no server logic |
| Frontend | **Boilerplate** — toolchain configured, no application features |
| Hardware design | **In progress** — KiCAD schematics and CAD models for EDF/ESC present |

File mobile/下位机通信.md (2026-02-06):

# 🛰️ AeroSmart 下位机通信指南 (V1.2)

本指南详细说明了 AeroSmart 项目中 **上位机服务 (Service)** 与 **下位机固件 (Firmware)** 之间，以及固件与底层传感器/执行器之间的通信机制。

---

## 1. 通信架构概览

AeroSmart 采用端到端的 Rust 协议栈，通过 **Monorepo** 结构确保协议在不同层级间的高度一致性。

*   **上位机 (Service)**: 运行于 PC/服务器，负责高层控制、数据记录与可视化。
*   **下位机 (Firmware)**: 运行于 STM32H7，负责实时控制、传感器采集与硬件抽象。
*   **共享层 (Shared)**: 定义了跨端通用的消息格式、序列化方案及数据库映射 (Scopes)。

---

## 2. 上位机 ↔ 下位机通信协议 (主协议)

### 2.1 物理层配置
*   **接口**: UART (USART1)
*   **波特率**: **915200 bps**
*   **引脚**: PA9 (TX), PA10 (RX)
*   **流控**: 无 (None)

### 2.2 握手与同步流程 (Handshake)

系统启动时必须进行一次握手，以同步时间并确认连接建立。此过程在固件 `main` 函数初始化阶段阻塞执行。

1.  **Ping (Firmware -> Service)**:
    *   固件初始化串口后，立即发送一个 `AcknowledgementData` 消息。
    *   Payload: `time_elapsed_ms` (系统启动后的毫秒数)。
2.  **Pong & Sync (Service -> Firmware)**:
    *   上位机收到 Ping 后，需回复一个 `AcknowledgementConfig` 消息。
    *   Payload: `ack = true`, `unix_timestamp_ms` (当前 UNIX 时间戳)。
3.  **Ready**:
    *   固件收到回复后，利用 `unix_timestamp_ms` 校准内部 RTC 时钟，随后启动所有异步任务 (UART RX/TX, Sensors, Control Loop)。

### 2.3 序列化方案
*   **框架**: **rkyv** (Zero-copy deserialization)。
*   **对齐**: 消息直接序列化为字节流传输，未显式使用 COBS/SLIP 封包。依赖底层传输可靠性。

---

## 3. 数据结构设计与 Scopes

所有通信消息封装在 `SerialMessage` 枚举中。数据结构设计不仅服务于通信，还通过 Feature Flags (如 `sql`) 定义了持久化 Scope。

### 3.1 控制指令 (Service -> Firmware)

| 消息类型 (Scope: Control) | 结构体 | 关键字段 | 说明 |
| :--- | :--- | :--- | :--- |
| **Command** | `Command` (Enum) | `Start`, `Stop`, `Calibrate` | **Start**: 进入 Running 状态<br>**Stop**: 进入 Idle 状态<br>**Calibrate**: 进入 Initializing 状态 |
| **ThrottleConfig** | `ThrottleConfig` | `airspeed` (u8) | 设定目标风速 (0-255 映射) |
| **ServoConfig** | `ServoConfig` | `angle` (u8) | 设定舵机角度 (0-255 映射) |
| **SensorConfig** | `SensorConfig` | `imu_horizontal` (bool) | 传感器安装方向配置 |
| **AcknowledgementConfig** | `AcknowledgementConfig` | `ack` (bool), `unix_timestamp_ms` (u64) | 握手与时间同步专用 |

### 3.2 遥测数据 (Firmware -> Service)

此类数据通常实现了 `to_record` 方法，支持直接映射为 SQL 数据库记录 (Scope: Persistence)。

#### 3.2.1 高频实时数据

| 消息类型 | 频率 | 结构体定义 | 数据库 Scope (Table) |
| :--- | :--- | :--- | :--- |
| **ImuData** | 20 Hz | `accel_z`, `gyro_x/y` (f32)<br>`quad_w/i/j/k` (f32, 四元数) | `imu_records` |
| **AcousticData** | 20 Hz | `overall_spl` (f32, 声压级)<br>`peak_frequency` (f32)<br>`spectral_shape` ([f32; 16], 频谱) | `acoustic_records` |
| **PitotAirspeedData** | 10 Hz | `splitter_left/right` (f32)<br>`static_port` (f32) | `pitot_records` |
| **AnalogPressureSensorData** | 10 Hz | `pressures_pa` ([f32; 4])<br>`valid_bitmask` (u8) | (待定) |

#### 3.2.2 低频监控数据

| 消息类型 | 频率 | 结构体定义 | 说明 |
| :--- | :--- | :--- | :--- |
| **LidarData** | 5 Hz | `distance_cm` (u16)<br>`signal_strength` (u16) | 激光雷达测距 |
| **ImuVibrationMetrics** | 1 Hz | `accel_z`, `gyro_x/y` (RMS, Peak, Freq) | 振动特征分析 |
| **BarometerData** | 1 Hz | `pressure_pa`, `temperature_c`, `humidity_percent` | 环境气象状态 |
| **BatteryData** | 1 Hz | `voltage_v` (f32)<br>`soc_percent` (f32) | 电源管理系统状态 |
| **QeiData** | Event | `position_counts` (u16)<br>`direction` (bool) | 旋钮/编码器交互 |
| **AcknowledgementData** | Once | `time_elapsed_ms` (u64) | 仅用于握手 Ping |

---

## 4. 固件 ↔ 传感器/执行器通信 (内部协议)

下位机通过硬件接口与外设交互，这些协议对上位机透明，但决定了数据的来源与精度。

### 4.1 激光雷达 (LiDAR)
*   **接口**: UART3 (PC10/PC11), 115200 bps
*   **协议**: TFmini-S 9字节定长帧 (`0x59 0x59 ...`)
*   **驱动**: `firmware/src/sensors/lidar_uart.rs`

### 4.2 空速与环境 (Pitot & Env)
*   **接口**: I2C1 (PB8/PB9), 400 kHz
*   **设备**:
    *   **MS4525DO**: 空速管差压传感器 (Addr: `0x28`)
    *   **BME280**: 温湿度气压传感器 (Addr: `0x76`/`0x77`)
*   **驱动**: `firmware/src/sensors/pitot_i2c.rs`

### 4.3 模拟气压阵列 (Analog Pressure)
*   **接口**: I2C3 (PA8/PC9), 400 kHz -> ADS1115 ADC
*   **设备**: XGZP6847A 等模拟输出传感器
*   **驱动**: `firmware/src/sensors/adc_i2c.rs`

### 4.4 惯性测量单元 (IMU)
*   **接口**: SPI1 (PB3/PB4/PB5), 1 MHz
*   **设备**: ICM-42688-P (6-Axis)
*   **驱动**: `firmware/src/sensors/imu_spi.rs`

### 4.5 动力系统 (EDF & Servo)
*   **EDF 风机**: TIM1 (PE9/PE11), **DShot600** 数字协议 (600 kHz)
*   **舵机**: TIM2 (PA0), 50 Hz PWM
*   **驱动**: `firmware/src/executors/edf.rs`, `servo.rs`

---

## 5. 调试与日志 (RTT)

*   **机制**: SEGGER RTT (Real Time Transfer)
*   **工具**: `defmt` (Logging) + `probe-rs` (Host side)
*   **用途**: 固件不占用 UART1 进行 `printf` 调试，确保通信带宽完全用于协议数据。

---

## 6. 开发注意事项

1.  **握手超时**: 上位机应在打开串口后立即监听 `AcknowledgementData`。若固件已启动，可能需发送 Reset 指令或设计重连机制（当前固件仅在启动时握手）。
2.  **数据对齐**: 由于未实现帧头同步，建议上位机在解析失败时清空缓冲区并重新尝试同步。
3.  **状态机**: 上位机需维护与固件一致的状态机 (`Idle` -> `Initializing` -> `Running`)，部分数据（如控制回路反馈）仅在 `Running` 状态下有效。

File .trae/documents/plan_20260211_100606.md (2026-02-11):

我已经完成了所有修复和国际化工作。

### 主要改动
1.  **修复遗漏的翻译**:
    -   在 `DashboardView.vue` 中找到了用户指出的 "Wind Input", "Pressure Difference Monitor" 以及其他遗漏的硬编码字符串（如 "Wind Speed Display", "Wind Direction" 等），并全部替换为 `$t(...)` 调用。
2.  **修复代码逻辑**:
    -   检查并修复了 `PowerView.vue` 中的一个 Bug：在 `watch` 函数中访问 `availableSources` 时缺少了 `.value`，这会导致运行时错误。
    -   确认 `ControlView.vue` 的代码逻辑正确，所有 `computed` 属性的使用都正确带上了 `.value`。
3.  **完善设置页面**:
    -   更新了 `SettingsModal.vue`，将硬编码的 `alert` 和 `confirm` 消息替换为国际化字符串。
4.  **验证**:
    -   使用 `grep` 搜索确认了所有关键的硬编码英文字符串（如 "Wind Input"）现在只存在于注释和翻译文件中，视图代码中已清除干净。

### 系统概览
-   **语言**: 支持 英文 (默认) 和 中文。
-   **状态管理**: 使用 Pinia 持久化存储用户语言偏好。
-   **响应式**: 所有图表配置、传感器列表和建议内容现在都是响应式的，切换语言时会立即更新，无需刷新页面。

现在您可以启动开发服务器并测试语言切换功能。所有界面元素，包括图表标题和动态生成的列表，都应该能正确显示中文。

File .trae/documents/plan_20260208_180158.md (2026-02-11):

# Frontend WebSocket Implementation Plan

## 1. WebSocket API Documentation

### Connection Details

* **URL**: `ws://localhost:3000/ws`

* **Protocol**: JSON over WebSocket

* **Serialization**: Rust `serde` Enum (External Tagging) -> `{"Variant": { ...fields... }}`

### Downlink (Server -> Client)

The server broadcasts telemetry data as JSON objects. The keys correspond to `SerialMessage` variants.

| Message Variant | JSON Structure Example | Target Store State |
| :--- | :--- | :--- |
| **ImuData** | `{"ImuData": {"accel_z": 9.8, "gyro_x": 0.1, "gyro_y": 0.1, "quad_w": 1.0, "quad_i": 0.0, "quad_j": 0.0, "quad_k": 0.0, "time_elapsed_ms": 1000}}` | `imu` (Need Quat->Euler conv) |
| **PitotAirspeedData** | `{"PitotAirspeedData": {"splitter_left": 12.0, "splitter_right": 12.0, "static_port": 1013.0, "time_elapsed_ms": 1000}}` | `airspeed` (Calculate velocity if needed or use raw) |
| **BatteryData** | `{"BatteryData": {"voltage_v": 12.6, "soc_percent": 95.0, "time_elapsed_ms": 1000}}` | `battery` |
| **LidarData** | `{"LidarData": {"distance_cm": 150, "signal_strength": 100, "time_elapsed_ms": 1000}}` | `lidar` |
| **BarometerData** | `{"BarometerData": {"pressure_pa": 101325, "temperature_c": 25.0, "humidity_percent": 50.0, "time_elapsed_ms": 1000}}` | `env` |
| **AcousticData** | `{"AcousticData": {"overall_spl": 80.0, "peak_frequency": 1000, "spectral_shape": [...], "turbulence_index": 0.5, "time_elapsed_ms": 1000}}` | `acoustic` |
| **AcknowledgementData** | `{"AcknowledgementData": {"time_elapsed_ms": 1000}}` | Connection Heartbeat |

### Uplink (Client -> Server)

The client sends control commands as JSON objects.

| Action | JSON Payload |
| :--- | :--- |
| **Set Throttle** | `{"ThrottleConfig": {"airspeed": <0-255>}}` |
| **Set Servo** | `{"ServoConfig": {"angle": <0-180>}}` |
| **Start System** | `{"Command": "Start"}` |
| **Stop System**  | `{"Command": "Stop"}` |
| **Calibrate** | `{"Command": "Calibrate"}` |

***

## 2. Implementation Steps

### Step 1: Update `panel/src/stores/device.ts`

* **Add WebSocket State**: `socket: WebSocket | null`, `reconnectTimer: any`.

* **Implement** **`connect()`** **action**:

  * Initialize `WebSocket`.

  * Bind `onopen` -> `isConnected = true`.

  * Bind `onclose`/`onerror` -> `isConnected = false`, trigger reconnection (3s delay).

  * Bind `onmessage` -> Parse JSON, dispatch to `handleMessage()`.

* **Implement** **`handleMessage(payload)`**:

  * Switch on object keys (`ImuData`, `BatteryData`, etc.).

  * Update reactive refs (`imu`, `battery`, `env`, etc.).

  * **Math Helper**: Implement `quaternionToEuler(w, x, y, z)` to update `imu.attitude` (Roll/Pitch/Yaw) for the UI.

* **Implement Control Actions**:

  * `setThrottle(val)`: `socket.send(JSON.stringify({"ThrottleConfig": {"airspeed": val}}))`

  * `setServo(val)`: `socket.send(JSON.stringify({"ServoConfig": {"angle": val}}))`

  * `sendCommand(cmd)`: `socket.send(JSON.stringify({"Command": cmd}))`

### Step 2: Integrate in `App.vue`

* Call `deviceStore.connect()` on mount to initiate the connection lifecycle.

### Step 3: Verify Data Mapping

* Ensure `PitotAirspeedData` mapping logic handles the raw pressure vs calculated airspeed (Note: Firmware `ThrottleConfig` uses `airspeed` field for throttle value, likely mapping 0-255. `PitotAirspeedData` returns raw sensor values).

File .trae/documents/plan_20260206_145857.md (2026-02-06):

# Service Implementation Plan: Serial Bridge & WebSocket

## 1. Project Structure & Dependencies
*   **Dependencies**: Ensure `service/Cargo.toml` includes `axum` (WebSocket support), `tokio` (runtime, sync), `tokio-serial` (serial port), `rkyv` (deserialization), `serde` & `serde_json` (JSON serialization for frontend), and `tracing` (logging).
*   **Architecture**:
    *   **Main Task**: Sets up channels, spawns the serial task, and runs the Axum server.
    *   **Serial Task**: Handles the physical layer (UART), handshake, and binary protocol (Rkyv).
    *   **Axum Handler**: Manages WebSocket connections, broadcasting telemetry, and forwarding commands.

## 2. Serial Communication Logic (Phase 1)
*   **Handshake**:
    *   Open the serial port (path via CLI arg, e.g., `/dev/tty.usbmodem...`).
    *   **Loop**: Read bytes looking for `SerialMessage::AcknowledgementData` (Ping).
    *   **Action**: Upon receipt, immediately send `SerialMessage::AcknowledgementConfig` (Pong) with the current Unix timestamp (`SystemTime`).
    *   **Transition**: Once handshaken, enter the main data loop.
*   **Main Loop (Uplink/Downlink)**:
    *   **Reading**: Read bytes from UART -> Deserialize `ArchivedSerialMessage` (Rkyv) -> Deserialize to Native Type -> Serialize to JSON -> Broadcast to WebSockets.
    *   **Writing**: Receive JSON command from WebSocket channel -> Deserialize to `SerialMessage` -> Serialize to Rkyv bytes -> Write to UART.

## 3. WebSocket Integration (Phase 2)
*   **Endpoint**: `GET /ws`
*   **Protocol**:
    *   **Server -> Client**: JSON string of telemetry data (e.g., `{"ImuData": {...}}`).
    *   **Client -> Server**: JSON string of control commands (e.g., `{"ThrottleConfig": {"airspeed": 100}}`).
*   **Concurrency**: Use `tokio::sync::broadcast` for fan-out telemetry and `tokio::sync::mpsc` for fan-in commands.

## 4. Implementation Details
*   **Error Handling**: No mocks. If serial fails to open or Rkyv fails to deserialize (after handshake), log error or panic as appropriate for a critical failure.
*   **Data Flow**:
    *   `Firmware` --(UART/Rkyv)--> `Serial Task` --(JSON)--> `Broadcast Channel` --(WS)--> `Frontend`
    *   `Frontend` --(WS/JSON)--> `Axum Handler` --(MPSC Channel)--> `Serial Task` --(UART/Rkyv)--> `Firmware`

## 5. Next Steps
*   Update `service/src/main.rs` with the full implementation.
*   The code will include the complete `SerialMessage` enum handling to ensure all defined types in `shared` are covered.

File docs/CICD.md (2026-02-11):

# CI/CD Pipeline for AeroSmart Panel

## Overview

This document describes the automated CI/CD pipeline for building the AeroSmart Panel Tauri application for OrangePi Zero 3 (aarch64).

## Architecture

```
┌─────────────────────────────────────────────────────────────┐
│                    GitHub Repository                         │
│                  aero-smart/aero-smart                       │
└────────────┬────────────────────────────────────────────────┘
             │
             │ Push to main / PR
             │ (panel/** or shared/** changes)
             │
             ▼
┌─────────────────────────────────────────────────────────────┐
│           GitHub Actions Workflow                            │
│         .github/workflows/build-aarch64.yml                  │
└────────────┬────────────────────────────────────────────────┘
             │
             ├─► Setup Environment
             │   ├── Rust toolchain (stable)
             │   ├── Node.js 24
             │   ├── pnpm 10.20.0
             │   └── Add aarch64-unknown-linux-gnu target
             │
             ├─► Install Cross-Compilation Dependencies
             │   ├── Add arm64 architecture to dpkg
             │   ├── Install aarch64 GCC/G++ toolchain
             │   ├── Install arm64 system libraries:
             │   │   ├── libwebkit2gtk-4.1-dev:arm64
             │   │   ├── libgtk-3-dev:arm64
             │   │   ├── libayatana-appindicator3-dev:arm64
             │   │   ├── librsvg2-dev:arm64
             │   │   ├── libssl-dev:arm64
             │   │   ├── libasound2-dev:arm64
             │   │   └── libdbus-1-dev:arm64
             │   └── Configure Cargo linker
             │
             ├─► Build Application
             │   ├── Install frontend dependencies (pnpm)
             │   ├── Build Tauri app for aarch64-unknown-linux-gnu
             │   └── Generate .deb package
             │
             └─► Upload Artifacts
                 ├── Debian package (.deb)
                 ├── AppImage (if generated)
                 └── BUILD_INFO.txt
                      ├── Branch name
                      ├── Commit SHA
                      ├── Build date
                      └── Target platform info
```

## Target Platform

**Hardware:** OrangePi Zero 3
- **CPU:** Allwinner H618 (4x Cortex-A53, 64-bit)
- **Architecture:** aarch64 (ARM64)
- **Display:** 1024x600 pixels

**Software Stack:**
- **OS:** Linux-based (Debian/Ubuntu compatible)
- **Runtime:** Tauri 2.x (WebView2 + Rust backend)
- **Display Mode:** Fullscreen, no decorations

## Build Triggers

The workflow is triggered automatically by:

1. **Push to main branch**
   - Only when files in `panel/**` or `shared/**` are modified
   - Or when the workflow file itself is modified

2. **Pull Requests**
   - Targeting the main branch
   - Affecting `panel/**` or `shared/**`

3. **Manual Trigger**
   - Via GitHub Actions UI (workflow_dispatch)

## Build Outputs

### Debian Package (.deb)
- **Location:** `panel/src-tauri/target/aarch64-unknown-linux-gnu/release/bundle/deb/`
- **Name Pattern:** `aero-smart-panel_<version>_arm64.deb`
- **Installation:**
  ```bash
  sudo dpkg -i aero-smart-panel_<version>_arm64.deb
  sudo apt-get install -f  # Install dependencies if needed
  ```

### AppImage (Optional)
- **Location:** `panel/src-tauri/target/aarch64-unknown-linux-gnu/release/bundle/appimage/`
- **Name Pattern:** `aero-smart-panel_<version>_aarch64.AppImage`
- **Usage:**
  ```bash
  chmod +x aero-smart-panel_<version>_aarch64.AppImage
  ./aero-smart-panel_<version>_aarch64.AppImage
  ```

## Artifacts Retention

- **Retention Period:** 30 days
- **Download:** Via GitHub Actions UI → workflow run → Artifacts section
- **Naming:** `aero-smart-panel-aarch64-<commit-sha>`

## Configuration Files

### Window Configuration
File: `panel/src-tauri/tauri.conf.json`

```json
{
  "app": {
    "windows": [
      {
        "title": "Aero Smart Panel",
        "width": 1024,
        "height": 600,
        "resizable": false,
        "fullscreen": true,
        "decorations": false,
        "alwaysOnTop": true,
        "skipTaskbar": true
      }
    ]
  }
}
```

### Cargo Configuration
The workflow automatically creates `~/.cargo/config.toml`:

```toml
[target.aarch64-unknown-linux-gnu]
linker = "aarch64-linux-gnu-gcc"
rustflags = ["-C", "link-arg=-Wl,--allow-multiple-definition"]
```

## Local Development

### Build Locally for aarch64

**Prerequisites:**
```bash
# Add arm64 architecture
sudo dpkg --add-architecture arm64

# Install cross-compilation toolchain
sudo apt-get install gcc-aarch64-linux-gnu g++-aarch64-linux-gnu

# Install arm64 dependencies (adjust sources.list first)
sudo apt-get install libwebkit2gtk-4.1-dev:arm64 \
  libgtk-3-dev:arm64 \
  libayatana-appindicator3-dev:arm64 \
  librsvg2-dev:arm64 \
  libssl-dev:arm64 \
  libasound2-dev:arm64 \
  libdbus-1-dev:arm64

# Add Rust target
rustup target add aarch64-unknown-linux-gnu
```

**Build Commands:**
```bash
# Option 1: Using npm script
cd panel
pnpm tauri:build:aarch64

# Option 2: Using just
just build-panel-aarch64

# Option 3: Using the Docker-based script
./build_aarch64.sh
```

## Testing on OrangePi Zero 3

1. Download the .deb artifact from GitHub Actions
2. Transfer to OrangePi:
   ```bash
   scp aero-smart-panel_*.deb pi@orangepi.local:~/
   ```
3. Install on OrangePi:
   ```bash
   sudo dpkg -i ~/aero-smart-panel_*.deb
   sudo apt-get install -f
   ```
4. Run:
   ```bash
   aero-smart-panel
   ```

## Troubleshooting

### Build Failures

**Issue:** Missing arm64 dependencies
- **Solution:** Check that all required arm64 libraries are installed
- The workflow includes `|| true` to continue even if some packages fail

**Issue:** Linker errors
- **Solution:** Verify cargo config has correct linker settings
- Check that gcc-aarch64-linux-gnu is installed

### Runtime Issues on Target

**Issue:** Missing shared libraries
- **Solution:** Install via apt on target device:
  ```bash
  sudo apt-get install libwebkit2gtk-4.1 libgtk-3-0 libayatana-appindicator3-1
  ```

**Issue:** Display not fullscreen
- **Solution:** Check tauri.conf.json has correct window settings
- Verify display resolution is 1024x600

## Related Files

- **Workflow:** `.github/workflows/build-aarch64.yml`
- **Tauri Config:** `panel/src-tauri/tauri.conf.json`
- **Package Scripts:** `panel/package.json`
- **Build Commands:** `justfile`
- **Docker Build:** `build_aarch64.sh`
- **Documentation:** `panel/README.md`, `README.md`

## Future Enhancements

- [ ] Add automatic release creation for tagged commits
- [ ] Support for other ARM platforms (Raspberry Pi, etc.)
- [ ] Code signing for releases
- [ ] Incremental builds with better caching
- [ ] Multi-architecture support (x86_64 + aarch64 in single workflow)

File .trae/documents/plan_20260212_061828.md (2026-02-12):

# Service 层 WiFi 连接适配与 Onboarding 优化计划

## 1. 后端 Service 层增强 (Rust)
### 功能：网络连通性测试
- **修改文件**: `service/src/wifi.rs`
- **新增功能**: 实现 `test_connectivity` 函数。
  - 逻辑：使用 `reqwest` 请求 `https://www.bilibili.com`。
  - 返回：成功返回 200 OK，失败返回错误信息。
- **路由注册**: 在 `service/src/main.rs` 中注册 `GET /api/wifi/test`。
- **依赖检查**: 确认 `reqwest` 包含 `rustls-tls` 或 `native-tls` 以支持 HTTPS。

## 2. 前端组件开发 (Vue)
### 新增组件：虚拟键盘 (`VirtualKeyboard.vue`)
- **位置**: `panel/src/components/VirtualKeyboard.vue`
- **布局**: QWERTY 全键盘布局，包含数字行、字母行、功能键（Shift, Backspace, Enter）。
- **交互**: 支持点击按键输入字符，支持 Shift 切换大小写/符号。
- **样式**: 针对触摸屏优化的大按键设计。

### API 客户端更新
- **修改文件**: `panel/src/api/wifi.ts`
- **新增方法**: `testWifiConnection()` 调用后端的测试接口。

### 状态管理更新
- **修改文件**: `panel/src/stores/wifi.ts`
- **新增 Action**: `testConnection()` 封装 API 调用，管理测试状态（testing/success/fail）。

## 3. Onboarding 页面改造
### 页面逻辑 (`OnboardingView.vue`)
- **集成 WiFi Store**: 使用 `useWifiStore` 获取网络列表。
- **UI 重构**:
  - **列表展示**: 美化 WiFi 列表项，增加信号强度图标。
  - **密码输入**: 点击加密网络时，显示包含密码框和虚拟键盘的模态层。
  - **连接流程**: 
    1. 用户输入密码并确认。
    2. 调用 `connect` 接口。
    3. 连接成功后，自动调用 `testConnection`。
    4. **连通性验证**: 只有当 `testConnection` 返回成功（Bilibili 可达）时，才显示“已连接”并允许点击“下一步”。
- **Kiosk 优化**: 确保键盘遮挡不影响输入框可见性。

## 4. 验证计划
- **Service**: `curl localhost:3000/api/wifi/test` 验证返回。
- **Frontend**: 
  - 检查虚拟键盘输入是否正常。
  - 模拟 WiFi 连接成功但无网的情况，确认流程被阻断。
  - 确认连接成功且有网时，流程顺畅。

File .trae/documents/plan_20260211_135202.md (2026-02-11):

# AeroSmart Bluez BLE (GATT) 重构计划

为适配 iOS 设备 (iOS 不支持经典蓝牙 RFCOMM SPP)，我们将把蓝牙栈从 **RFCOMM** 迁移到 **BLE (Bluetooth Low Energy)**，采用通用的 **Nordic UART Service (NUS)** 方案来实现“串口透传”。

## 1. 架构变更

*   **传输层**: 从 `RFCOMM Socket` 变更为 `GATT Service`。
*   **服务定义 (NUS)**:
    *   **Service UUID**: `6E400001-B5A3-F393-E0A9-E50E24DCCA9E`
    *   **RX Characteristic (App Write)**: `6E400002-B5A3-F393-E0A9-E50E24DCCA9E` (属性: `Write` / `WriteWithoutResponse`)
    *   **TX Characteristic (App Notify)**: `6E400003-B5A3-F393-E0A9-E50E24DCCA9E` (属性: `Notify`)
*   **协议层**: 保持原有的 `BtFrame` 协议 (Header+Len+Payload+Checksum) 不变，将其作为 Byte Stream 运行在 NUS 上。

## 2. 模块重构 (`service/src/bluetooth/`)

### 2.1 `service.rs` (核心重构)

*   **移除**: `bluer::Profile` (RFCOMM) 相关代码。
*   **新增**: `bluer::gatt::{App, Service, Characteristic}` 相关代码。
*   **逻辑变更**:
    *   **广播 (Advertisement)**: 配置 LE Advertisement，广播 NUS Service UUID，确保 iOS 能发现设备。
    *   **GATT Application**: 注册 NUS 服务。
    *   **Write Handler (RX)**: 实现 `Write` 回调，接收 App 发来的 Byte 数据 -> `try_parse_frame` -> `Converter` -> `cmd_tx`。
    *   **Notify Handler (TX)**: 维护一个 `Notify` 句柄 (或通过 `CharacteristicControl` 句柄)，当 `broadcast` 收到内部消息时 -> `Converter` -> `BtFrame` -> `to_bytes` -> 发送 Notification。

### 2.2 `codec.rs` & `converter.rs`

*   **保持不变**: 协议解析逻辑与业务转换逻辑与传输层解耦，可直接复用。

## 3. 详细实施步骤

1.  **修改 `service/src/bluetooth/service.rs`**:
    *   定义 NUS UUID 常量。
    *   重写 `run_bluetooth_service`：
        *   获取 Bluez Adapter。
        *   开启 Power。
        *   注册 `Advertisement` (包含 Local Name "AeroSmart" 和 Service UUID)。
        *   注册 `GATT Application`。
        *   建立 `mpsc` 通道或 `Arc<Mutex<...>>` 来桥接 GATT 回调与主业务逻辑。由于 `bluer` 的 GATT 回调是异步的，我们需要将 `cmd_tx` 传递给 Write Handler，并将 TX Characteristic 的 Writer 暴露给 `broadcast` 接收循环。

2.  **处理 MTU**:
    *   BLE 通知通常限制在 20 字节 (默认) 或更高 (取决于协商)。
    *   我们将尝试直接发送 `BtFrame` 的字节。如果 Frame 较长，`bluer` 或底层 Bluez 通常会自动分包，或者 App 端需要处理分包重组。鉴于 `BtFrame` 有 Header 和 Len，接收端 (App) 容易处理粘包/半包。

## 4. 验证计划

*   **编译检查**: 确保 `bluer` 的 GATT API 使用正确。
*   **逻辑验证**: 依赖原有的单元测试保证协议正确性。
*   **部署测试 (建议)**: 部署到 Linux 设备后，使用 iOS 上的 "nRF Connect" 或 "LightBlue" App 连接 "AeroSmart" 设备，订阅 TX 特征值并向 RX 特征值写入指令进行测试。

请确认此 BLE 重构计划。

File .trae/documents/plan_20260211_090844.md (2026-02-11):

I will implement a robust internationalization (i18n) system for the frontend as requested.

### 1. Dependencies & Setup
- **Install `vue-i18n`**: Add the standard Vue i18n library to `package.json`.
- **Initialize i18n**: Create `src/i18n.ts` to configure the i18n instance with English (default) and Chinese support.
- **Main Entry**: Update `src/main.ts` to use the i18n plugin.

### 2. State Management (Pinia)
- **Create `src/stores/locale.ts`**: 
  - Manage the current language state (`'en' | 'zh'`).
  - Persist the user's choice to `localStorage` so it survives page reloads.
  - Provide actions to switch languages, which will update both the Pinia state and the `i18n` instance locale.

### 3. Translation Resources
- **Create `src/locales/en.ts`**: Move all hardcoded English strings here.
- **Create `src/locales/zh.ts`**: Provide Chinese translations for the same keys.
- **Structure**:
  - `common`: General terms (Settings, Save, Cancel).
  - `nav`: Sidebar navigation items (Overview, Sensor, Data).
  - `settings`: specific strings for the Settings modal (Serial, Server, Debug Mode, etc.).

### 4. Component Implementation
- **`src/components/SettingsModal.vue`**:
  - Add a "Language" / "语言" selection section (Dropdown or Toggle).
  - Replace hardcoded titles ("Settings", "Serial Communication") and labels with `$t(...)`.
- **`src/components/layout/Sidebar.vue`**:
  - Update menu items to use translated labels.
  - Update tooltips to use translated strings.

### 5. Verification
- **Test**: Verify that switching the language in Settings updates the UI immediately and persists after refresh.

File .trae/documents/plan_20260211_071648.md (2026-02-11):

# 实现 AeroSmart Onboarding 页面

## 1. 后端配置修改 (Tauri/Rust)

我们需要在 `AeroSmart.toml` 中添加一个新参数 `enable_onboarding` 来控制是否显示 Onboarding 页面。

- **文件**: `panel/src-tauri/src/config.rs`
- **任务**:
  - 在 `RulesConfig` 结构体中添加 `pub enable_onboarding: bool`。
  - 在 `Default` 实现中设置默认值为 `true`。
  - 更新 `create_default_config_file_if_missing` 函数中的模板字符串，包含此新配置项及其注释。
- **目的**: 允许用户通过配置文件启用或禁用 Onboarding 流程。

## 2. 前端路由与视图 (Vue)

创建一个新的视图组件用于 Onboarding，并配置路由。

- **文件**: `panel/src/views/OnboardingView.vue` (新建)
- **任务**:
  - 创建一个全屏 Flex/Grid 布局的页面。
  - **动画效果**: 使用 Vue 的 `<Transition>` 组件或 CSS `transition` 实现淡入淡出 (Fade In/Out)。
  - **内容**:
    - **Logo**: 居中显示 AeroSmart Logo，带有弹入动画 (Scale/Fade In)。
    - **按钮**: "开始使用" (Get Started)，带有 Hover 效果。
  - **交互**: 点击按钮后，导航至主页 (`/`)。

- **文件**: `panel/src/router/index.ts`
- **任务**:
  - 添加 `/onboarding` 路由，指向 `OnboardingView.vue`。

## 3. 前端状态管理与启动逻辑 (Store/App)

在应用启动时检查配置，并决定是否跳转到 Onboarding 页面。

- **文件**: `panel/src/stores/device.ts` (或其他合适的 Store)
- **任务**:
  - 添加一个 Action 或在 `connect` 逻辑中，增加获取后端配置的能力（如果尚未实现，可能需要通过 Tauri Command 获取配置，或者简单点，通过 WebSocket 的初始握手/状态消息传递此配置）。
  - **替代方案 (推荐)**: 由于前端直接读取后端 TOML 比较麻烦，我们可以通过 Tauri Command 暴露配置，或者在 WebSocket 连接建立后的第一个消息中包含此信息。
  - **简化方案**: 鉴于目前是 WebSocket 通信，我们可以新增一个 Tauri Command `get_app_config` 来专门获取配置给前端。

- **文件**: `panel/src-tauri/src/lib.rs`
- **任务**:
  - 注册一个新的 Tauri Command `get_app_config`，返回 `AppConfig` 结构体给前端。

- **文件**: `panel/src/App.vue` 或 `panel/src/router/index.ts` (路由守卫)
- **任务**:
  - 在应用挂载 (`onMounted`) 或路由前置守卫中，调用 `get_app_config`。
  - 如果 `config.rules.enable_onboarding` 为 `true` 且用户尚未完成 Onboarding (可以使用 `localStorage` 标记作为辅助，但需求是强依赖配置文件)，则跳转到 `/onboarding`。
  - *修正*: 用户的需求是“用配置文件的参数判断是否在前端启动的时候展示”。这意味着每次启动只要配置为 true 就展示，或者配置为 true 时才检查本地状态。我们将严格遵循“配置文件决定”的逻辑。

## 实施步骤

1.  **后端**: 修改 `config.rs` 添加 `enable_onboarding` 字段。
2.  **后端**: 在 `lib.rs` 中实现并注册 `get_app_config` Tauri 命令。
3.  **前端**: 创建 `src/views/OnboardingView.vue`，实现 UI 和动画。
4.  **前端**: 更新 `src/router/index.ts` 添加路由。
5.  **前端**: 修改 `src/App.vue`，在启动时调用 `get_app_config` 并根据结果跳转。

## 验证计划

1.  修改 `AeroSmart.toml` 设置 `enable_onboarding = true`，重启应用，确认进入 Onboarding 页面。
2.  点击“开始使用”，确认能平滑过渡到主页。
3.  修改 `AeroSmart.toml` 设置 `enable_onboarding = false`，重启应用，确认直接进入主页。

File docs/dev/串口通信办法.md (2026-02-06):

toolName: view_folder
            
status: success
          
/Users/jiangyin14/dev/web-serial-debug-main

toolName: view_files
            
status: success

filePath: /Users/jiangyin14/dev/web-serial-debug-main/index.html

toolName: view_files
            
status: success

filePath: /Users/jiangyin14/dev/web-serial-debug-main/js/common.js
          
这份《Web Serial Debug 项目技术分析文档》深入剖析了项目基于 Web Serial API 实现串口通信的核心机制。

***

# Web Serial Debug 项目技术分析文档

## 1. 项目概述
本项目是一个基于 Web 技术的串口调试工具，利用现代浏览器提供的 `Web Serial API` 实现与本地串口设备的直接通信。项目采用纯静态架构（HTML + CSS + JS），无需后端服务，完全在浏览器端运行。

**核心功能：**
*   串口参数配置（波特率、校验位等）
*   串口数据的实时收发
*   多种数据格式支持（Hex, Text, Ansi）
*   快捷指令集管理
*   可编程脚本处理（Web Worker）

---

## 2. 核心业务逻辑分析

### 2.1 浏览器兼容性与初始化
项目启动时首先检查浏览器对 `navigator.serial` 的支持情况，这是 Web Serial API 的入口。

**相关代码 (`js/common.js`):**
```javascript
if (!('serial' in navigator)) {
    alert('当前浏览器不支持串口操作,请更换Edge或Chrome浏览器')
}
let serialPort = null
// 尝试获取已授权的端口
navigator.serial.getPorts().then((ports) => {
    if (ports.length > 0) {
        serialPort = ports[0]
        serialStatuChange(true)
    }
})
```

### 2.2 串口连接管理
连接管理分为“请求授权”和“打开连接”两个步骤。这是 Web 安全模型的要求，必须由用户主动触发（通常是点击事件）。

**请求用户授权串口:**
```javascript
document.getElementById('serial-select-port').addEventListener('click', async () => {
    try {
        // 弹出浏览器原生串口选择框
        await navigator.serial.requestPort().then(async (port) => {
            closeSerial()
            serialPort = port // 保存选中的端口对象
            serialStatuChange(true)
        })
    } catch (e) {
        console.error('获取串口权限出错' + e.toString())
    }
})
```

**打开串口连接:**
在获取 `serialPort` 对象后，需要使用用户配置的参数（波特率、停止位等）实际打开连接。
```javascript
async function openSerial() {
    let SerialOptions = {
        baudRate: parseInt(get('serial-baud')),
        dataBits: parseInt(get('serial-data-bits')),
        stopBits: parseInt(get('serial-stop-bits')),
        parity: get('serial-parity'),
        bufferSize: parseInt(get('serial-buffer-size')),
        flowControl: get('serial-flow-control'),
    }
    
    serialPort.open(SerialOptions).then(() => {
        serialOpen = true
        readData() // 打开成功后立即启动读取循环
    })
    // ... Error handling
}
```

### 2.3 数据读取实现
数据读取是一个持续的异步过程。项目使用 `while` 循环配合 `reader.read()` 来不断从串口缓冲区拉取数据。

**核心读取循环:**
```javascript
async function readData() {
    // 只要串口是打开状态且可读，就持续循环
    while (serialOpen && serialPort.readable) {
        reader = serialPort.readable.getReader()
        try {
            while (true) {
                const { value, done } = await reader.read()
                if (done) {
                    break // 读写器已被锁定或释放
                }
                dataReceived(value) // 处理接收到的 Uint8Array 数据
            }
        } catch (error) {
            // 处理读取错误
        } finally {
            reader.releaseLock() // 必须释放锁，以便稍后重新获取
        }
    }
    await serialPort.close()
}
```

**分包合并逻辑:**
串口数据往往是分片到达的。项目通过一个定时器 (`serialTimer`) 实现了简单的分包合并逻辑：收到数据后不立即处理，而是重置定时器，直到一段时间（默认50ms）没有新数据到达，才认为一包数据接收完毕。

```javascript
function dataReceived(data) {
    serialData.push(...data) // 将新数据追加到缓冲区
    
    // 如果设置了超时时间
    if (toolOptions.timeOut == 0) {
        // ... 直接处理
        return
    }
    
    // 清除之前的定时器，防抖动
    clearTimeout(serialTimer)
    serialTimer = setTimeout(() => {
        // 超时后认为包结束，进行处理
        addLog(serialData, true)
        serialData = [] // 清空缓冲区
    }, toolOptions.timeOut)
}
```

### 2.4 数据发送实现
数据发送通过获取 `writable` 流的 `writer` 来实现。支持文本和十六进制两种模式。

**通用发送函数:**
```javascript
async function writeData(data) {
    if (!serialPort || !serialPort.writable) {
        return
    }
    const writer = serialPort.writable.getWriter()
    
    // 可选：添加回车换行 (CRLF)
    if (toolOptions.addCRLF) {
        data = new Uint8Array([...data, 0x0d, 0x0a])
    }
    
    await writer.write(data) // 写入数据
    writer.releaseLock()     // 释放锁
    addLog(data, false)      // 记录发送日志
}
```

**文本发送:**
使用 `TextEncoder` 将字符串转换为 `Uint8Array`。
```javascript
async function sendText(text) {
    const encoder = new TextEncoder()
    writeData(encoder.encode(text))
}
```

**Hex 发送:**
将十六进制字符串解析为数值数组，再转换为 `Uint8Array`。
```javascript
async function sendHex(hex) {
    const value = hex.replace(/\s+/g, '') // 去除空格
    if (/^[0-9A-Fa-f]+$/.test(value) && value.length % 2 === 0) {
        let data = []
        for (let i = 0; i < value.length; i = i + 2) {
            data.push(parseInt(value.substring(i, i + 2), 16))
        }
        await writeData(Uint8Array.from(data))
    }
    // ... Error handling
}
```

## 3. 高级功能：脚本化处理
项目允许用户编写 JavaScript 脚本来自动化处理串口数据。这是通过 `Web Worker` 实现的，确保用户脚本不会阻塞主线程（UI 线程）。

**Worker 创建与通信:**
```javascript
// 将用户编写的代码转换为 Blob URL
var blob = new Blob([editor.getValue()], { type: 'text/javascript' })
worker = new Worker(window.URL.createObjectURL(blob))

// 监听 Worker 发回的消息
worker.onmessage = function (e) {
    if (e.data.type == 'uart_send') {
        writeData(new Uint8Array(e.data.data)) // 脚本请求发送数据
    }
    // ... 其他操作
}

// 收到串口数据时转发给 Worker
// 在 dataReceived 函数中：
if (worker) {
    worker.postMessage({ type: 'uart_receive', data: serialData })
}
```

## 4. 总结
该项目展示了 Web Serial API 的标准最佳实践：
1.  **流式处理**：正确使用了 `ReadableStream` 和 `WritableStream` 的 reader/writer 锁机制。
2.  **异步编程**：大量使用 `async/await` 处理 I/O 操作，避免阻塞。
3.  **二进制处理**：核心数据流均基于 `Uint8Array`，配合 `TextEncoder`/`TextDecoder` 进行文本转换。
4.  **安全隔离**：利用 Web Worker 隔离用户自定义脚本，保证核心通信功能的稳定性。

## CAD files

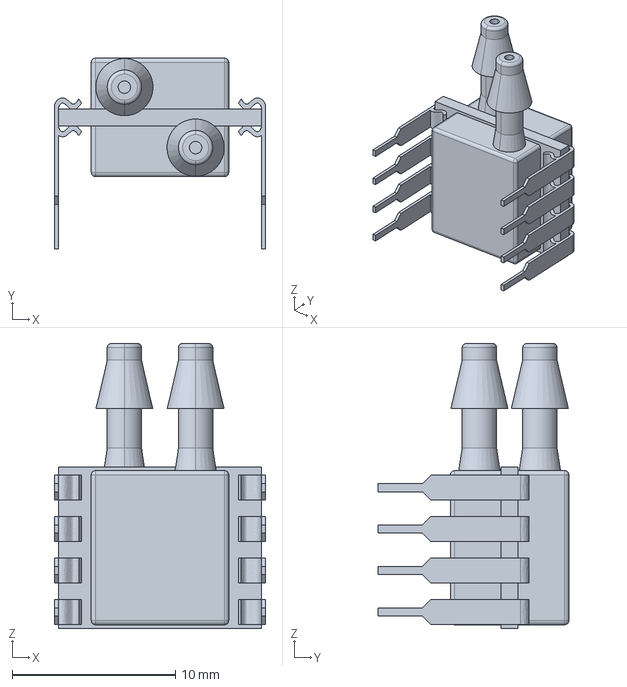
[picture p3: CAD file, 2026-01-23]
schematics/imports/4525DO-DS5AI001DP/4525DO-DS5AI001DP.step
13.0 x 11.7 x 17.5 mm

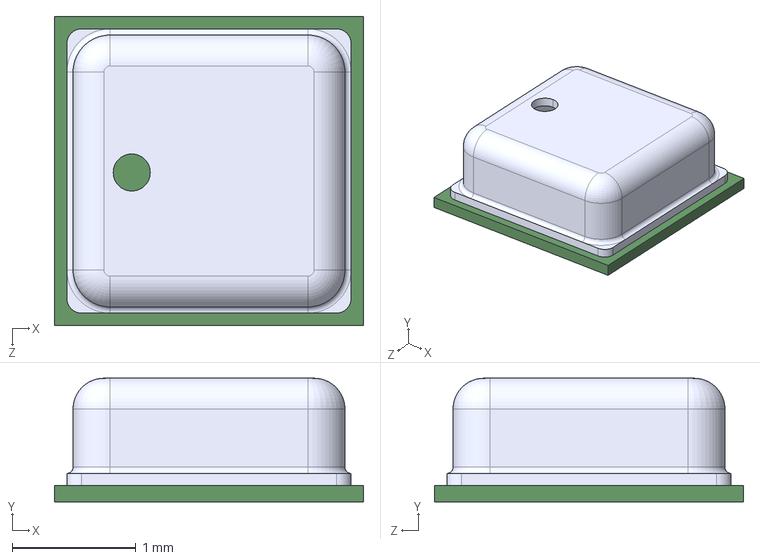
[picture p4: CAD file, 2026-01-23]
schematics/imports/BME280/BME280.step
2.50 x 1.00 x 2.50 mm

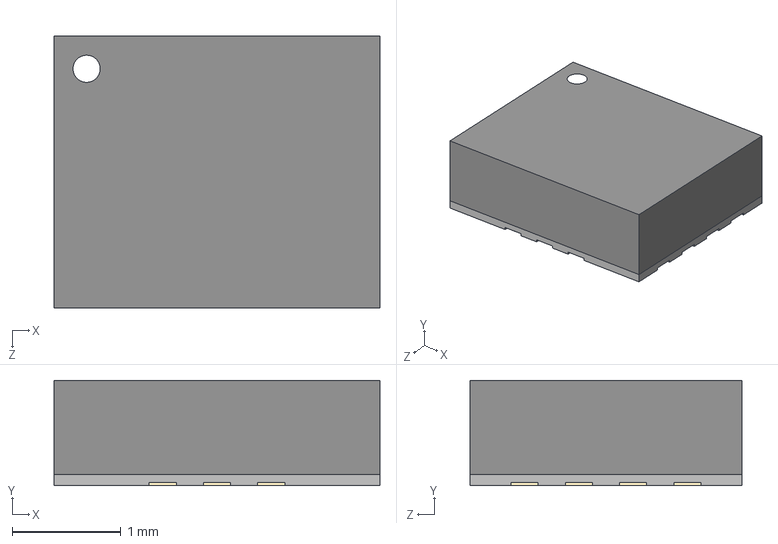
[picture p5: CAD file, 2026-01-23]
schematics/imports/ICM-42688-P/ICM-42688-P.step
3.00 x 0.97 x 2.50 mm

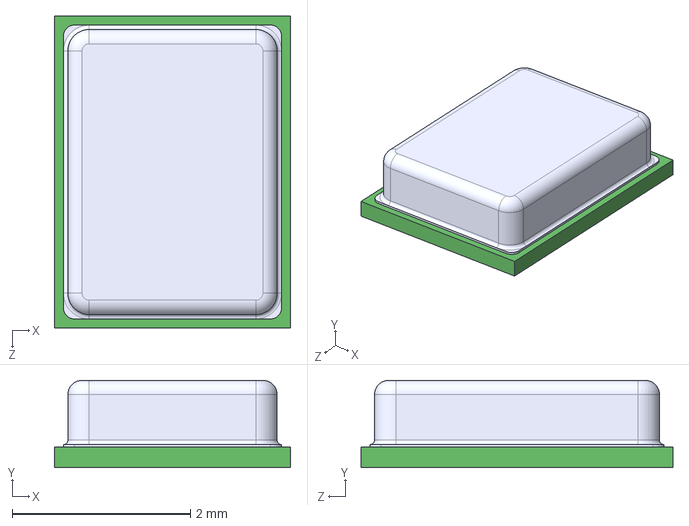
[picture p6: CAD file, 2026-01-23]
schematics/imports/ICS-43434/ICS-43434.step
2.65 x 0.98 x 3.50 mm

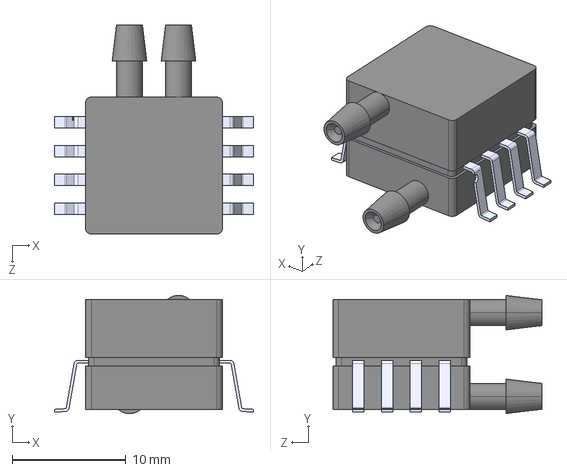
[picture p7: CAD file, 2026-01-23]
schematics/imports/MPXV7002DP/MPXV7002DP.step
17.5 x 10.4 x 18.4 mm

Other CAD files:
model/2.7.f3z
model/edf2.f3d
model/esc_1_2.7.f3d
model/flow.f3d
model/y_2.11.f3d

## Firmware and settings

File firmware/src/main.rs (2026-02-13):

#![no_std]
#![no_main]

pub mod algorithms;
pub mod consts;
pub mod executors;
pub mod sensors;
pub mod state;
pub mod tasks;
#[macro_use]
pub mod utils;

use crate::{
    algorithms::{airspeed::AirspeedControl, madgwick::MadgwickAhrs},
    consts::{
        algorithms::{MADGWICK_BETA, PID_KD, PID_KI, PID_KP},
        sensors::{
            EDF_PWM_FREQUENCY_HZ, I2C_FREQ_KHZ, IMU_SAMPLE_RATE_HZ, LIDAR_BAUD_RATE,
            SERVO_PWM_FREQUENCY_HZ, UPPER_BAUD_RATE,
        },
    },
    executors::{edf_pwm::EdfPwm, servo::Servo},
    sensors::{
        audio_i2s::Audio,
        drivers::icm_42688_p::{AccelConfig0, GyroConfig0},
        imu_spi::ImuSpi,
        lidar_uart::LidarUart,
        pitot_i2c::Airspeed,
    },
    state::{AUDIO_CHANNEL, GLOBAL_STATE, SAI_BUFFER},
    tasks::*,
};

use {defmt_rtt as _, panic_probe as _};

use aerosmart_shared::serial::SerialMessage;
use defmt::info;
use embassy_executor::Spawner;
use embassy_futures::join;
use embassy_stm32::{
    adc::Adc,
    bind_interrupts,
    exti::ExtiInput,
    gpio::{Level, Output, Pull, Speed},
    i2c::{self, I2c},
    rtc::{Rtc, RtcConfig},
    sai::{Sai, split_subblocks},
    spi::{self, Spi},
    time::Hertz,
    timer::simple_pwm::{PwmPin, PwmPinConfig, SimplePwm},
    usart::Uart,
    wdg::IndependentWatchdog,
};
use embassy_time::{Duration, TICK_HZ, Timer, with_timeout};
use ws2812_async::{Rgb, Ws2812};

bind_interrupts!(struct Irqs {
    I2C1_EV => i2c::EventInterruptHandler<embassy_stm32::peripherals::I2C1>;
    I2C1_ER => i2c::ErrorInterruptHandler<embassy_stm32::peripherals::I2C1>;
    I2C3_EV => i2c::EventInterruptHandler<embassy_stm32::peripherals::I2C3>;
    I2C3_ER => i2c::ErrorInterruptHandler<embassy_stm32::peripherals::I2C3>;
    USART1 => embassy_stm32::usart::InterruptHandler<embassy_stm32::peripherals::USART1>;
    USART3 => embassy_stm32::usart::InterruptHandler<embassy_stm32::peripherals::USART3>;
});

#[derive(defmt::Format)]
pub struct TestConfig {
    pub i2s: bool,
    pub spi_imu: bool,
    pub spi_ws2812: bool,
    pub uart_upper: bool,
    pub uart_lidar: bool,
    pub i2c: bool,
    pub pwm_edf: bool,
    pub pwm_servo: bool,
    pub wdt: bool,
    pub fft: bool,
    pub ahrs: bool,
    pub ctrl_airspeed: bool,
    pub battery_adc: bool,
    pub analog_pressure: bool,
}

fn get_stm_config() -> embassy_stm32::Config {
    let mut config = embassy_stm32::Config::default();
    let dbgmcu = embassy_stm32::pac::DBGMCU;
    dbgmcu.cr().modify(|w| {
        w.set_dbgsleep_d1(true);
        w.set_dbgstby_d1(true);
        w.set_dbgstop_d1(true);
    });
    {
        info!("The tick frequency is {} Hz", TICK_HZ);
        use embassy_stm32::rcc::*;
        config.rcc.hsi = Some(HSIPrescaler::DIV4);
        config.rcc.hse = Some(Hse {
            freq: Hertz::mhz(400),
            mode: HseMode::Oscillator,
        });
        config.rcc.csi = true;
        config.rcc.hsi48 = Some(Default::default()); // needed for RNG
        config.rcc.pll1 = Some(Pll {
            source: PllSource::HSI,
            prediv: PllPreDiv::DIV4,
            mul: PllMul::MUL50,
            divp: Some(PllDiv::DIV2),
            divq: Some(PllDiv::DIV1),
            divr: None,
        });
        config.rcc.pll2 = Some(Pll {
            source: PllSource::HSI,
            prediv: PllPreDiv::DIV4,
            mul: PllMul::MUL50,
            divp: Some(PllDiv::DIV8),
            divq: None,
            divr: None,
        });
        config.rcc.sys = Sysclk::PLL1_P;
        config.rcc.ahb_pre = AHBPrescaler::DIV2;
        config.rcc.apb1_pre = APBPrescaler::DIV2;
        config.rcc.apb2_pre = APBPrescaler::DIV2;
        config.rcc.apb3_pre = APBPrescaler::DIV2;
        config.rcc.apb4_pre = APBPrescaler::DIV2;
        config.rcc.voltage_scale = VoltageScale::Scale1;
    }
    config
}

#[embassy_executor::main]
async fn main(spawner: Spawner) {
    let p = embassy_stm32::init(get_stm_config());

    info!("AeroSmart Firmware Starting...");

    let config = TestConfig {
        i2s: false,
        spi_imu: true,
        spi_ws2812: false,
        uart_upper: true,
        uart_lidar: false,
        i2c: true,
        pwm_edf: true,
        pwm_servo: false,
        wdt: true,
        fft: true,
        ahrs: false,
        ctrl_airspeed: true,
        battery_adc: false,
        analog_pressure: true,
    };

    info!("Configuration: {:?}", config);

    let mut wdt = IndependentWatchdog::new(p.IWDG1, 20_000_000);

    wdt.unleash();

    info!("Watchdog initialized with 20s timeout");

    let mut spi_config = spi::Config::default();

    spi_config.frequency = Hertz::mhz(1);

    let spi = Spi::new(
        p.SPI1, p.PB3, p.PB5, p.PB4, p.DMA1_CH0, p.DMA1_CH1, spi_config,
    );

    info!("SPI1 initialized for IMU");

    fn i2c_config_with_freq(freq: Hertz) -> i2c::Config {
        let mut config = i2c::Config::default();
        config.frequency = freq;
        config
    }

    let i2c = I2c::new(
        p.I2C1,
        p.PB8,
        p.PB9,
        Irqs,
        p.DMA1_CH2,
        p.DMA1_CH3,
        i2c_config_with_freq(Hertz::khz(I2C_FREQ_KHZ)),
    );

    info!("I2C1 initialized for Airspeed Sensor & Barometer");

    let i2c_adc = I2c::new(
        p.I2C3,
        p.PA8,
        p.PC9,
        Irqs,
        p.DMA2_CH4,
        p.DMA2_CH5,
        i2c_config_with_freq(Hertz::khz(I2C_FREQ_KHZ)),
    );

    info!("I2C4 initialized for ADCs (using ADS1115 chip)");

    let i2c_analog_drdy = ExtiInput::new(p.PC8, p.EXTI8, Pull::Up);

    // The `MPXV7002` hasn't been purchased and we don't have one to test with yet
    let analog_adc = sensors::adc_i2c::AdcI2c::new(
        i2c_adc,
        Some(sensors::adc_i2c::AdcConnection::Xgzp6847a {
            max_pressure_pa: 3_000.0,
        }),
        Some(sensors::adc_i2c::AdcConnection::Xgzp6847a {
            max_pressure_pa: 2_500.0,
        }),
        None,
        None,
        i2c_analog_drdy,
    );

    fn uart_config_with_baud(baud_rate: u32) -> embassy_stm32::usart::Config {
        let mut config = embassy_stm32::usart::Config::default();
        config.baudrate = baud_rate;
        config
    }

    let Ok(mut usart_upper) = Uart::new(
        p.USART1,
        p.PA10,
        p.PA9,
        Irqs,
        p.DMA2_CH0,
        p.DMA2_CH1,
        uart_config_with_baud(UPPER_BAUD_RATE),
    ) else {
        defmt::panic!("Failed to initialize upper USART");
    };

    let mut rtc = Rtc::new(p.RTC, RtcConfig::default());

    if config.uart_upper {
        const MAX_RETRIES: u32 = 10;
        let mut success = false;

        for attempt in 1..=MAX_RETRIES {
            let result = with_timeout(
                Duration::from_secs(3),
                serial_initialize(&mut usart_upper, &mut rtc),
            )
            .await;

            match result {
                Ok(_) => {
                    info!("RTC synchronized via UART");
                    success = true;
                    break;
                }
                Err(_) => {
                    defmt::warn!(
                        "RTC synchronization via UART timed out (attempt {}/{})",
                        attempt,
                        MAX_RETRIES
                    );
                    if attempt < MAX_RETRIES {
                        // Optional: add a small delay between retries
                        // embassy_time::Timer::after(Duration::from_millis(100)).await;
                    }
                }
            }
        }

        if !success {
            defmt::error!(
                "RTC synchronization failed after {} attempts, performing software reset",
                MAX_RETRIES
            );
            cortex_m::peripheral::SCB::sys_reset();
        }
    }

    let (uart_tx, uart_rx) = usart_upper.split();

    info!("USART1 initialized for upper serial communication");

    let Ok(usart_lidar) = Uart::new(
        p.USART3,
        p.PC11,
        p.PC10,
        Irqs,
        p.DMA1_CH6,
        p.DMA1_CH7,
        uart_config_with_baud(LIDAR_BAUD_RATE),
    ) else {
        defmt::panic!("Failed to initialize LIDAR USART");
    };

    let lidar = LidarUart::new(usart_lidar);

    info!("USART3 initialized for LIDAR communication");

    fn pull_down_config() -> PwmPinConfig {
        PwmPinConfig {
            output_type: embassy_stm32::gpio::OutputType::PushPull,
            speed: Speed::VeryHigh,
            pull: Pull::Down,
        }
    }

    let left_esc_servo = PwmPin::new_with_config(p.PA0, pull_down_config());
    let right_esc_servo = PwmPin::new_with_config(p.PA1, pull_down_config());

    let edf_servo_pwm = SimplePwm::new(
        p.TIM5,
        Some(left_esc_servo),
        Some(right_esc_servo),
        None,
        None,
        Hertz::hz(EDF_PWM_FREQUENCY_HZ),
        embassy_stm32::timer::low_level::CountingMode::EdgeAlignedUp,
    );

    info!("TIM1 initialized for EDF ESC control");

    let servo = PwmPin::new(p.PA2, embassy_stm32::gpio::OutputType::PushPull);

    let servo_pwm = SimplePwm::new(
        p.TIM2,
        None,
        None,
        Some(servo),
        None,
        Hertz::hz(SERVO_PWM_FREQUENCY_HZ),
        embassy_stm32::timer::low_level::CountingMode::EdgeAlignedUp,
    );

    let servo_control = Servo::new(servo_pwm);

    info!("TIM2 initialized for Servo control");

    let ws2812_spi = Spi::new_txonly(p.SPI2, p.PD3, p.PC3, p.DMA1_CH4, spi::Config::default());
    let ws2812: Ws2812<_, Rgb, 1> = Ws2812::new(ws2812_spi);

    info!("SPI2 initialized for WS2812 LED control");

    let icm_ss = Output::new(p.PB2, Level::High, Speed::VeryHigh);
    let mut imu = ImuSpi::new(spi, icm_ss, AccelConfig0::default(), GyroConfig0::default());
    let icm_drdy = ExtiInput::new(p.PB1, p.EXTI1, Pull::Up);

    info!("IMU SPI interface initialized");

    let mut sensors = Airspeed::new(i2c);
    let edf = EdfPwm::new(edf_servo_pwm);
    let pid = AirspeedControl::new(0.0, PID_KP, PID_KI, PID_KD);
    let ahrs = MadgwickAhrs::new(IMU_SAMPLE_RATE_HZ as f32 * 10.0, MADGWICK_BETA);

    info!("Airspeed sensor and EDF driver initialized");

    let adc1 = Adc::new(p.ADC1);

    let (sai_tx_conf, sai_rx_conf) = sai_config_ltrr();

    let (sai_rx_p, sai_tx_p) = split_subblocks(p.SAI1);

    let (sai_tx_buffer, sai_rx_buffer): (&mut [u32], &mut [u32]) = unsafe {
        let buf = &mut *core::ptr::addr_of_mut!(SAI_BUFFER);
        let ptr = buf.as_mut_ptr();
        let len = buf.len();
        let slice = core::slice::from_raw_parts_mut(ptr, len);
        slice.split_at_mut(512)
    };

    let sai_rx = Sai::new_asynchronous_with_mclk(
        sai_rx_p,
        p.PE5,
        p.PE6,
        p.PE4,
        p.PE2,
        p.DMA2_CH7,
        sai_rx_buffer,
        sai_rx_conf,
    );

    let sai_tx = Sai::new_synchronous(sai_tx_p, p.PE3, p.DMA2_CH6, sai_tx_buffer, sai_tx_conf);

    let microphone = Audio::new(sai_rx, sai_tx);

    wdt.pet();

    // ws2812.write([RGB8::new(0, 32, 0), RGB8::default()].into_iter()).await.ok();

    info!("System initialized, starting tasks...");

    match (config.spi_imu, config.i2c) {
        (true, true) => match join::join(imu.init(), sensors.init()).await {
            (Ok(_), Ok(_)) => info!("IMU and Airspeed Sensor initialized successfully"),
            (Err(e1), Err(e2)) => defmt::panic!(
                "Failed to initialize IMU and Airspeed Sensor: {:?}, {:?}",
                e1,
                e2
            ),
            (Err(e), _) => defmt::panic!("Failed to initialize IMU: {:?}", e),
            (_, Err(e)) => defmt::panic!("Failed to initialize Airspeed Sensor: {:?}", e),
        },
        (true, false) => {
            info!("Starting IMU initialization...");
            match imu.init().await {
                Ok(_) => info!("IMU initialized successfully"),
                Err(e) => defmt::panic!("Failed to initialize IMU: {:?}", e),
            }
        }
        (false, true) => {
            info!("Starting Airspeed Sensor initialization...");
            match sensors.init().await {
                Ok(_) => info!("Airspeed Sensor initialized successfully"),
                Err(e) => defmt::panic!("Failed to initialize Airspeed Sensor: {:?}", e),
            }
        }
        (false, false) => { /* No sensors to initialize */ }
    }

    match spawner.spawn(watchdog_task(wdt)) {
        Ok(_) => info!("Watchdog task spawned"),
        Err(e) => defmt::panic!("Failed to spawn watchdog task: {:?}", e),
    }

    if config.uart_lidar {
        info!("Starting LIDAR task...");
        match spawner.spawn(lidar_task(lidar)) {
            Ok(_) => info!("LIDAR task spawned"),
            Err(e) => defmt::panic!("Failed to spawn LIDAR task: {:?}", e),
        }
    }

    if config.spi_imu {
        info!("Starting IMU task...");
        match spawner.spawn(imu_task(imu, icm_drdy, ahrs)) {
            Ok(_) => info!("IMU task spawned"),
            Err(e) => defmt::panic!("Failed to spawn IMU task: {:?}", e),
        }
    }

    if config.i2c {
        info!("Starting Airspeed task...");
        match spawner.spawn(airspeed_task(sensors)) {
            Ok(_) => info!("Airspeed task spawned"),
            Err(e) => defmt::panic!("Failed to spawn airspeed task: {:?}", e),
        }
    }

    if config.pwm_edf {
        info!("Starting EDF task...");
        match spawner.spawn(edf_task(edf, pid)) {
            Ok(_) => info!("EDF task spawned"),
            Err(e) => defmt::panic!("Failed to spawn EDF task: {:?}", e),
        }
    }

    if config.spi_ws2812 {
        info!("Starting LED task...");
        match spawner.spawn(led_task(ws2812)) {
            Ok(_) => info!("LED task spawned"),
            Err(e) => defmt::panic!("Failed to spawn LED task: {:?}", e),
        }
    }

    if config.fft {
        info!("Starting IMU FFT task...");
        match spawner.spawn(imu_fft_task()) {
            Ok(_) => info!("IMU FFT task spawned"),
            Err(e) => defmt::panic!("Failed to spawn IMU FFT task: {:?}", e),
        }
    }

    if config.pwm_servo {
        info!("Starting Airspeed Servo task...");
        match spawner.spawn(servo_task(servo_control)) {
            Ok(_) => info!("Airspeed Servo task spawned"),
            Err(e) => defmt::panic!("Failed to spawn Airspeed Servo task: {:?}", e),
        }
    }

    if config.uart_upper {
        info!("Starting Serial UART RX task...");
        match spawner.spawn(serial_uart_rx_task(uart_rx)) {
            Ok(_) => info!("Serial UART RX task spawned"),
            Err(e) => defmt::panic!("Failed to spawn Serial UART RX task: {:?}", e),
        }

        info!("Starting Serial UART TX task...");
        match spawner.spawn(serial_uart_tx_task(uart_tx)) {
            Ok(_) => info!("Serial UART TX task spawned"),
            Err(e) => defmt::panic!("Failed to spawn Serial UART TX task: {:?}", e),
        }
    }

    if config.battery_adc {
        info!("Starting Battery Monitoring task...");
        match spawner.spawn(battery_task(adc1, p.PA3, p.DMA2_CH3)) {
            Ok(_) => info!("Battery Monitoring task spawned"),
            Err(e) => defmt::panic!("Failed to spawn Battery Monitoring task: {:?}", e),
        }
    }

    if config.analog_pressure {
        info!("Starting Analog Pressure Sensor task...");
        match spawner.spawn(analog_pressure_task(analog_adc)) {
            Ok(_) => info!("Analog Pressure Sensor task spawned"),
            Err(e) => defmt::panic!("Failed to spawn Analog Pressure Sensor task: {:?}", e),
        }
    }

    if config.i2s {
        info!("Starting Acoustic Sampling task...");
        match spawner.spawn(acoustic_sampling_task(microphone, AUDIO_CHANNEL.sender())) {
            Ok(_) => info!("Acoustic Audio task spawned"),
            Err(e) => defmt::panic!("Failed to spawn Acoustic Audio task: {:?}", e),
        }
        info!("Starting Acoustic Analysis task...");
        match spawner.spawn(acoustic_analysis_task(AUDIO_CHANNEL.receiver())) {
            Ok(_) => info!("Acoustic Analysis task spawned"),
            Err(e) => defmt::panic!("Failed to spawn Acoustic Analysis task: {:?}", e),
        }
    }
}

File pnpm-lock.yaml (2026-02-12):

lockfileVersion: '9.0'

settings:
  autoInstallPeers: true
  excludeLinksFromLockfile: false

importers:

  .: {}

  docs:
    dependencies:
      vitepress:
        specifier: ^1.6.4
        version: 1.6.4(@algolia/client-search@5.48.0)(@types/node@24.10.11)(async-validator@4.2.5)(lightningcss@1.31.1)(postcss@8.5.6)(sass@1.97.3)(search-insights@2.17.3)(typescript@5.9.3)

  panel:
    dependencies:
      '@element-plus/icons-vue':
        specifier: ^2.3.2
        version: 2.3.2(vue@3.5.27(typescript@5.9.3))
      '@tauri-apps/api':
        specifier: ^2.10.0
        version: 2.10.1
      echarts:
        specifier: ^6.0.0
        version: 6.0.0
      element-plus:
        specifier: ^2.13.2
        version: 2.13.2(vue@3.5.27(typescript@5.9.3))
      lucide-vue-next:
        specifier: ^0.563.0
        version: 0.563.0(vue@3.5.27(typescript@5.9.3))
      pinia:
        specifier: ^3.0.4
        version: 3.0.4(typescript@5.9.3)(vue@3.5.27(typescript@5.9.3))
      qrcode.vue:
        specifier: ^3.8.0
        version: 3.8.0(vue@3.5.27(typescript@5.9.3))
      sass:
        specifier: ^1.97.3
        version: 1.97.3
      vue:
        specifier: ^3.5.26
        version: 3.5.27(typescript@5.9.3)
      vue-i18n:
        specifier: ^11.2.8
        version: 11.2.8(vue@3.5.27(typescript@5.9.3))
      vue-router:
        specifier: ^4.6.4
        version: 4.6.4(vue@3.5.27(typescript@5.9.3))
    devDependencies:
      '@playwright/test':
        specifier: ^1.57.0
        version: 1.58.2
      '@tauri-apps/cli':
        specifier: ^2.10.0
        version: 2.10.0
      '@tsconfig/node24':
        specifier: ^24.0.3
        version: 24.0.4
      '@types/jsdom':
        specifier: ^27.0.0
        version: 27.0.0
      '@types/node':
        specifier: ^24.10.4
        version: 24.10.11
      '@vitejs/plugin-vue':
        specifier: ^6.0.3
        version: 6.0.4(vite@8.0.0-beta.14(@types/node@24.10.11)(esbuild@0.27.3)(jiti@2.6.1)(sass@1.97.3))(vue@3.5.27(typescript@5.9.3))
      '@vitejs/plugin-vue-jsx':
        specifier: ^5.1.3
        version: 5.1.4(vite@8.0.0-beta.14(@types/node@24.10.11)(esbuild@0.27.3)(jiti@2.6.1)(sass@1.97.3))(vue@3.5.27(typescript@5.9.3))
      '@vitest/eslint-plugin':
        specifier: ^1.6.5
        version: 1.6.6(eslint@9.39.2(jiti@2.6.1))(typescript@5.9.3)(vitest@4.0.18(@types/node@24.10.11)(jiti@2.6.1)(jsdom@27.4.0)(lightningcss@1.31.1)(sass@1.97.3))
      '@vue/eslint-config-prettier':
        specifier: ^10.2.0
        version: 10.2.0(eslint@9.39.2(jiti@2.6.1))(prettier@3.7.4)
      '@vue/eslint-config-typescript':
        specifier: ^14.6.0
        version: 14.6.0(eslint-plugin-vue@10.6.2(@typescript-eslint/parser@8.54.0(eslint@9.39.2(jiti@2.6.1))(typescript@5.9.3))(eslint@9.39.2(jiti@2.6.1))(vue-eslint-parser@10.2.0(eslint@9.39.2(jiti@2.6.1))))(eslint@9.39.2(jiti@2.6.1))(typescript@5.9.3)
      '@vue/test-utils':
        specifier: ^2.4.6
        version: 2.4.6
      '@vue/tsconfig':
        specifier: ^0.8.1
        version: 0.8.1(typescript@5.9.3)(vue@3.5.27(typescript@5.9.3))
      autoprefixer:
        specifier: ^10.4.24
        version: 10.4.24(postcss@8.5.6)
      eslint:
        specifier: ^9.39.2
        version: 9.39.2(jiti@2.6.1)
      eslint-plugin-oxlint:
        specifier: ~1.38.0
        version: 1.38.0
      eslint-plugin-playwright:
        specifier: ^2.4.0
        version: 2.5.1(eslint@9.39.2(jiti@2.6.1))
      eslint-plugin-vue:
        specifier: ~10.6.2
        version: 10.6.2(@typescript-eslint/parser@8.54.0(eslint@9.39.2(jiti@2.6.1))(typescript@5.9.3))(eslint@9.39.2(jiti@2.6.1))(vue-eslint-parser@10.2.0(eslint@9.39.2(jiti@2.6.1)))
      jiti:
        specifier: ^2.6.1
        version: 2.6.1
      jsdom:
        specifier: ^27.4.0
        version: 27.4.0
      npm-run-all2:
        specifier: ^8.0.4
        version: 8.0.4
      oxfmt:
        specifier: ^0.28.0
        version: 0.28.0
      oxlint:
        specifier: ~1.38.0
        version: 1.38.0(oxlint-tsgolint@0.12.0)
      oxlint-tsgolint:
        specifier: ^0.12.0
        version: 0.12.0
      postcss:
        specifier: ^8.5.6
        version: 8.5.6
      prettier:
        specifier: 3.7.4
        version: 3.7.4
      tailwindcss:
        specifier: ^3.4.17
        version: 3.4.19
      typescript:
        specifier: ~5.9.3
        version: 5.9.3
      vite:
        specifier: beta
        version: 8.0.0-beta.14(@types/node@24.10.11)(esbuild@0.27.3)(jiti@2.6.1)(sass@1.97.3)
      vite-plugin-vue-devtools:
        specifier: ^8.0.5
        version: 8.0.6(vite@8.0.0-beta.14(@types/node@24.10.11)(esbuild@0.27.3)(jiti@2.6.1)(sass@1.97.3))(vue@3.5.27(typescript@5.9.3))
      vitest:
        specifier: ^4.0.16
        version: 4.0.18(@types/node@24.10.11)(jiti@2.6.1)(jsdom@27.4.0)(lightningcss@1.31.1)(sass@1.97.3)
      vue-tsc:
        specifier: ^3.2.2
        version: 3.2.4(typescript@5.9.3)
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

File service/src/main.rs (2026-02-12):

use aerosmart_shared::serial::{AcknowledgementConfig, ArchivedSerialMessage, SerialMessage};
use anyhow::Context;
use axum::{
    Router,
    extract::{
        State,
        ws::{Message, WebSocket, WebSocketUpgrade},
    },
    response::IntoResponse,
    routing::{get, post},
};
use clap::Parser;
use std::{
    net::SocketAddr,
    time::{Duration, SystemTime, UNIX_EPOCH},
};

mod wifi;
use tokio::{
    io::{AsyncReadExt, AsyncWriteExt},
    sync::{broadcast, mpsc},
    time::timeout,
};
use tokio_serial::SerialPortBuilderExt;
use tower_http::cors::CorsLayer;
use tracing::{error, info, warn};

/// AeroSmart Service
#[derive(Parser, Debug)]
#[command(version, about, long_about = None)]
struct Args {
    /// Serial port name (e.g., /dev/tty.usbmodem1234 or COM3)
    #[arg(short, long, default_value = "/dev/tty.usbmodem1234")]
    port: String,

    /// Baud rate
    #[arg(short, long, default_value_t = 915200)]
    baud: u32,
}

#[derive(Clone)]
struct AppState {
    tx: broadcast::Sender<String>,
    cmd_tx: mpsc::Sender<SerialMessage>,
}

#[tokio::main]
async fn main() -> anyhow::Result<()> {
    // Initialize logging
    tracing_subscriber::fmt::init();

    let args = Args::parse();
    info!(
        "Starting AeroSmart Service on port {} @ {}",
        args.port, args.baud
    );

    // Channels
    // Broadcast: Serial -> WebSockets (Telemetry JSON)
    let (tx, _rx) = broadcast::channel::<String>(100);
    // MPSC: WebSockets -> Serial (Command SerialMessage)
    let (cmd_tx, mut cmd_rx) = mpsc::channel::<SerialMessage>(100);

    let state = AppState {
        tx: tx.clone(),
        cmd_tx: cmd_tx.clone(),
    };

    // Spawn Serial Task
    let port_name = args.port.clone();
    let baud_rate = args.baud;
    tokio::spawn(async move {
        // Retry loop for serial connection
        loop {
            if let Err(e) = serial_task(port_name.clone(), baud_rate, tx.clone(), &mut cmd_rx).await
            {
                error!("Serial task failed: {:?}. Retrying in 5s...", e);
                tokio::time::sleep(Duration::from_secs(5)).await;
            }
        }
    });

    // Setup Axum Router
    let app = Router::new()
        .route("/ws", get(ws_handler))
        .route("/api/wifi/scan", get(wifi::scan_handler))
        .route("/api/wifi/connect", post(wifi::connect_handler))
        .route("/api/wifi/disconnect", post(wifi::disconnect_handler))
        .route("/api/wifi/status", get(wifi::status_handler))
        .route("/api/wifi/test", get(wifi::test_handler))
        .layer(CorsLayer::permissive())
        .with_state(state);

    let addr = SocketAddr::from(([0, 0, 0, 0], 3000));
    info!("Listening on {}", addr);
    let listener = tokio::net::TcpListener::bind(addr).await?;
    axum::serve(listener, app).await?;

    Ok(())
}

async fn serial_task(
    port_name: String,
    baud_rate: u32,
    tx: broadcast::Sender<String>,
    cmd_rx: &mut mpsc::Receiver<SerialMessage>,
) -> anyhow::Result<()> {
    info!("Opening serial port {}...", port_name);
    let mut port = tokio_serial::new(&port_name, baud_rate)
        .open_native_async()
        .context("Failed to open serial port")?;

    #[cfg(unix)]
    port.set_exclusive(false)
        .context("Failed to set exclusive mode")?;

    info!("Serial port opened. Waiting for Handshake (Ping)...");

    // --- Phase 1: Handshake (Length-Prefixed) ---
    // We expect the firmware to send: [u32 len] [payload]
    // The payload should be AcknowledgementData.
    loop {
        let len = match timeout(Duration::from_secs(2), port.read_u32_le()).await {
            Ok(Ok(len)) => len as usize,
            Ok(Err(e)) => {
                warn!("Handshake read error: {:?}", e);
                continue;
            }
            Err(_) => {
                // Timeout, waiting for firmware
                continue;
            }
        };

        if len > 1024 {
            warn!("Invalid handshake packet length: {}", len);
            // Try to flush/recover? For now just continue reading.
            continue;
        }

        let mut buf = vec![0u8; len];
        port.read_exact(&mut buf)
            .await
            .context("Failed to read handshake payload")?;

        let valid_ping = match rkyv::access::<ArchivedSerialMessage, rkyv::rancor::Error>(&buf) {
            Ok(archived) => match archived {
                ArchivedSerialMessage::AcknowledgementData(_) => true,
                _ => false,
            },
            Err(_) => false,
        };

        if valid_ping {
            info!("Received Ping. Sending Pong...");

            let now = SystemTime::now()
                .duration_since(UNIX_EPOCH)
                .unwrap()
                .as_millis() as u64;

            let pong = SerialMessage::AcknowledgementConfig(AcknowledgementConfig {
                ack: true,
                unix_timestamp_ms: now,
            });

            // let bytes = serialize_message(&pong)?;
            let bytes = rkyv::to_bytes::<rkyv::rancor::Error>(&pong)
                .map_err(|e| anyhow::anyhow!("Serialization error: {:?}", e))?;

            // Send Length Prefix (u32 little-endian)
            let len = bytes.len() as u32;
            port.write_all(&len.to_le_bytes())
                .await
                .context("Failed to write handshake length prefix")?;

            port.write_all(&bytes).await?;
            info!("Pong sent. Handshake complete. Entering Main Loop.");
            break;
        } else {
            warn!("Received non-ping message during handshake");
        }
    }

    // --- Phase 2: Main Loop ---
    loop {
        tokio::select! {
            // Uplink: Serial -> WebSocket
            // 1. Read Length (u32)
            res = port.read_u32_le() => {
                let len = match res {
                    Ok(l) => l as usize,
                    Err(e) => {
                        return Err(anyhow::anyhow!("Serial read error: {:?}", e));
                    }
                };

                if len > 4096 {
                     warn!("Oversized packet: {}. Skipping...", len);
                     // In a real stream, we would need to re-sync.
                     // Since we read exactly 4 bytes, we might be misaligned.
                     // But with length-prefix, if we are aligned, we stay aligned.
                     continue;
                }

                // 2. Read Payload
                let mut buf = vec![0u8; len];
                port.read_exact(&mut buf).await.context("Failed to read payload")?;
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

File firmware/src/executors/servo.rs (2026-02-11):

use embassy_stm32::{peripherals::TIM2, timer::simple_pwm::SimplePwm};

pub struct Servo<'a> {
    pub pwm: SimplePwm<'a, TIM2>,
}

impl<'a> Servo<'a> {
    pub fn new(pwm: SimplePwm<'a, TIM2>) -> Self {
        Servo { pwm }
    }

    pub fn set_angle_deg(&mut self, angle_deg: f32) {
        // Assuming 0 degrees corresponds to 1ms pulse and 180 degrees to 2ms pulse
        let pulse_width_ms = 1.0 + (angle_deg / 180.0);
        let period_ms = 20.0; // Standard servo period of 20ms
        let duty_cycle = (pulse_width_ms / period_ms) * 100.0;

        self.pwm.ch3().set_duty_cycle_percent(duty_cycle as u8);
    }

    pub fn enable(&mut self) {
        self.pwm.ch3().enable();
    }
}

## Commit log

2026-01-21 feat(schematics): add components of first edition
    [lower-level.kicad_pcb, lower-level.kicad_sch]
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2026-01-23 feat: schematics and basic driver code
    [lower-level.kicad_pcb, lower-level.kicad_sch]
2026-01-23 chore(schematics): add symbols
    [4525DO-DS5AI001DP.step, BME280.step, ICM-42688-P.step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]
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2026-01-24 refactor(firmware): send message should not block the mutex
    [lower-level.kicad_sch]
2026-01-29 Add EDF_1.30 CAD model
    [EDF_1.30_s.step]
2026-01-30 feat: implement `icm` and `bme` driver
    [lower-level.kicad_sch]
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2026-01-30 “idk”
    [EDF_1.31.f3d]
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2026-02-01 feat(shared): update serial
    [lower-level.kicad_sch]
2026-02-03 fix: add clock for adc
    [main.rs]
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2026-02-06 feat(device): 实现 WebSocket 连接与数据实时处理
    - 在设备存储中集成 WebSocket 客户端，支持自动重连
    - 添加消息处理器，将服务器推送的传感器数据映射至前端状态
    - 实现控制命令发送功能（油门、舵机、系统命令）
    - 在应用挂载时自动建立 WebSocket 连接
2026-02-07 chore(docs): move documentations to a delicated folder
    [lower-level.kicad_sch]
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2026-02-09 chore: add edf test logic
    [powerfb.kicad_pcb, powerfb.kicad_sch]
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2026-02-11 model summary
    [EDF_2.7.f3d, edf2.f3d, flow.f3d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]
2026-02-11 ci: 简化CI配置并调整aarch64构建的产物处理
    删除原有的动态CI工作流，简化CI配置。调整aarch64构建工作流中的产物查找路径，专注于打包AppImage文件并更新BUILD_INFO信息。
    - 删除复杂的动态CI检测工作流（ci.yml），减少维护复杂度
    - 更新aarch64构建中的产物查找路径，从panel/src-tauri/target改为target根目录
    - 仅上传AppImage文件作为构建产物，移除对deb包的打包支持
    - 更新BUILD_INFO.txt，移除固定的显示分辨率信息
2026-02-11 fix: 更新默认串口端口为 /dev/ttyUSB0
    将默认串口端口从 /dev/tty.usbserial-AZ1DF9AN 更改为更通用的 /dev/ttyUSB0，
    以适配更常见的硬件环境，提高开箱即用体验。
2026-02-11 fix: 修正Linux下配置文件路径并更新包名
    - 将Cargo.toml中的包名从"app"改为"aspanel"
    - 在Linux系统上将配置文件路径从当前目录改为~/.AeroSmart.toml
    - 更新CI工作流以同时打包AppImage和Deb格式的安装包
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2026-02-11 feat(ui): 优化仪表盘和控制面板布局及交互
    - 调整侧边栏宽度和图标尺寸以改善视觉平衡
    - 移除仪表盘顶部标签页，简化界面
    - 优化仪表盘网格布局，改进组件间距和对齐
    - 移除控制面板中的传感器拖拽和编辑功能，简化操作
    - 为AI建议添加分页功能，提升长列表浏览体验
    - 添加Tauri窗口类型声明以支持桌面端集成
    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
2026-02-11 feat(ui): 优化仪表盘和控制面板的视觉布局与交互
    - 调整仪表盘风速表尺寸和样式，改进信息卡片设计
    - 重构控制面板AI建议区域，移除输入框改为预设卡片
    - 增加预设建议数量，优化分页按钮样式和布局
2026-02-11 feat(router): 新增 PowerView 并调整预设卡片布局
    - 添加 PowerView 用于实时和历史功率分析，包含波形图表和数据导出功能
    - 将原 analysis 路由指向 PowerView 组件
    - 调整 ControlView 中预设卡片的响应式网格布局，从固定列数改为自适应
    - 减少每页显示的预设建议数量从 8 个到 6 个，并移除两个预设项
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2026-02-11 feat(i18n): 为前端面板添加国际化支持
    - 安装并配置 vue-i18n 库
    - 创建中英文翻译文件 (en.ts, zh.ts)
    - 使用 Pinia store 管理用户语言偏好并持久化存储
    - 在设置模态框中添加语言切换功能
    - 更新侧边栏、仪表板、控制面板等所有视图组件，替换硬编码字符串为国际化调用
    - 修复控制面板中访问计算属性缺少 .value 的潜在错误
    - 更新配置文件，调整默认串口和启用调试模式
2026-02-11 feat(mobile): 初始化 Flutter 移动端应用项目
    添加 Flutter 移动端应用的基础项目结构，包含：
    - Android 和 iOS 平台配置文件、启动图标和启动画面
    - 核心应用架构：Material Design 主题、GoRouter 路由配置
    - 主要功能页面：仪表盘、监控、控制、设置和固件更新页面
    - 状态管理：使用 Riverpod 实现各页面的状态管理
    - 项目文档：应用规格说明书和基础 README
    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
2026-02-11 feat(panel): 新增WiFi管理功能及设置页面
    - 添加WiFi管理组件，支持扫描、连接、断开网络
    - 创建设置视图并集成到路由中
    - 实现后端WiFi API接口，支持网络扫描、连接、断开和状态查询
    - 添加前端API客户端和Pinia状态管理
    - 移除旧的Settings.vue文件，重命名为SettingsView.vue
    - 添加蓝牙重构计划文档
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2026-02-11 feat: update control panel layout and sensors (resize buttons, pagination, unit conversion)
2026-02-11 feat(panel): 重构 PowerView 界面布局与交互设计
    - 将侧边栏改为独立区域，优化数据源选择样式为卡片式交互
    - 添加实时数据仪表盘，支持分页显示当前数值
    - 改进图表工具提示格式与样式，增强可读性
    - 引入响应式布局，根据容器宽度自动调整仪表盘显示数量
    - 统一图标使用并优化整体视觉层次
2026-02-12 fix: apply scale factor for imu
    [imu_spi.rs, main.rs]
2026-02-12 Add onboarding process with wifi setup, terms acceptance, and calibra… (#7)
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2026-02-12 fix(panel): 修复 PowerView.vue 中的合并冲突和语法错误
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2026-02-12 feat: 实现设备绑定与WiFi连接验证功能
    - 新增移动端设备绑定流程，包含二维码扫描与蓝牙配网页面
    - 添加移动端依赖：mobile_scanner、flutter_blue_plus、permission_handler
    - 后端新增WiFi连通性测试接口，验证bilibili.com可达性
    - 前端面板新增虚拟键盘组件，优化触摸屏输入体验
    - 增强WiFi连接流程，连接成功后自动测试网络连通性
    - 更新iOS和Android权限配置，支持相机和蓝牙功能
    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
2026-02-12 style(panel): 格式化 Vue 组件代码并更新依赖配置
    - 为多个 Vue 组件（Container, PageLayout, Grid, Input, Card, Badge, Button 等）添加尾随逗号并格式化模板属性
    - 在 vite 配置中格式化条件判断语句
    - 更新 Tailwind 配置中的阴影键名格式（移除引号）
    - 格式化 CSS 变量定义中的注释间距
    - 在 Rust 服务中格式化错误信息字符串
    - 更新 Cargo.toml 中的 reqwest 依赖以禁用默认特性并使用 rustls
    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
2026-02-12 feat(panel): 添加跳过WiFi连接选项并改进错误处理
    - 在WiFi设置步骤中添加"跳过"按钮，允许用户跳过网络连接
    - 改进WiFi API错误处理，返回服务器错误详情而非通用消息
    - 自动启用Linux系统的WiFi适配器，提升扫描成功率
    - 标准化配置文件处理，为缺失字段填充默认值
    - 将构建命令从npm切换至pnpm以提高性能
2026-02-12 fix: 修复触摸设备上的滚动和缩放问题
    调整视图元标签以禁止用户缩放，并为主内容区域添加滚动支持
    修复跳过WiFi连接后步骤递增错误
    为图表添加数据缩放功能以改善触摸交互
2026-02-12 fix(wifi): 统一错误响应格式为JSON并改进前端错误处理
    后端将错误响应从纯文本改为结构化的JSON格式（{ "error": "message" }），
    前端相应更新错误处理逻辑以优先解析JSON错误信息，保持错误消息的一致性。
2026-02-12 style: 格式化前端代码以提升可读性和一致性
    - 在 Vue 组件和 HTML 中调整长属性以遵循多行格式
    - 修复 CSS 中错误的属性嵌套，确保样式正确应用
    - 在 TypeScript 文件中统一使用分号
    - 调整 Rust 代码格式以保持简洁
2026-02-12 fix(wifi): 修复错误处理中响应文本读取顺序问题
    调整错误处理逻辑，先读取响应文本再尝试解析JSON，避免在解析失败时无法获取原始错误信息
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2026-02-12 feat(onboarding): 重构并增强用户引导流程的UI与交互
    - 采用现代化卡片式设计，包含渐变背景与阴影效果
    - 引入分步骤进度指示器，提供更清晰的视觉反馈
    - 集成WiFi扫描与连接功能，支持网络状态测试与错误处理
    - 添加虚拟键盘组件，优化移动端输入体验
    - 增加校准步骤，包含传感器校准项目
    - 实现模态对话框用于WiFi密码输入和跳过确认
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2026-02-12 feat(wifi): 增强Linux平台WiFi扫描的可靠性和日志记录
    添加条件编译确保非Linux平台不引入不必要的依赖
    在解析扫描输出时增加详细的调试日志，便于排查问题
    改进扫描失败后的重试逻辑，添加更多状态日志
    非Linux平台现在会记录警告信息并返回空列表
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2026-02-12 feat(wifi): 添加 WiFi 管理 API 端点
    - 新增 WiFi 扫描、连接、断开连接、状态查询和连通性测试的 API 端点
    - 实现基于 `nmcli` 的 Linux 平台 WiFi 操作，非 Linux 平台返回不支持错误
    - 配置文件中默认串口端口现在根据目标操作系统动态设置
2026-02-12 feat(ui): 在侧边栏添加WiFi状态指示器并改进虚拟键盘布局
    - 在侧边栏添加WiFi连接状态指示器，显示网络连接状态和SSID
    - 重构虚拟键盘组件，支持符号输入模式和多页符号布局
    - 优化键盘UI样式，改进触摸交互体验
    - 调整导入语句顺序以符合代码规范
    - 修复配置文件模板的格式问题
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2026-02-12 feat(激活流程): 引入设备激活流程和虚拟键盘集成
    - 新增键盘状态管理 store，用于集中管理虚拟键盘的显示、输入和回调逻辑
    - 在设置模态框的串口和服务器配置输入框中集成虚拟键盘，提升触摸屏输入体验
    - 重构 WiFi 管理组件，改进 UI 并添加自动扫描和键盘集成
    - 在侧边栏添加 WiFi 管理模态框入口
    - 实现设备激活后端逻辑，包括激活状态机、硬件时钟同步和串口连接等待机制
    - 将 onboarding 流程的第三步从校准改为激活，包含状态显示和激活按钮
    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
2026-02-12 fix(面板): 修复引导流程中的布局和交互问题
    调整各步骤容器的布局以改善滚动和溢出行为
    为激活步骤添加跳过功能，允许在出错时通过多次点击跳过
    修复步骤导航逻辑，支持已跳过的激活状态
2026-02-12 feat(serial): 添加串行连接状态管理及前端指示器
    - 新增 Pinia store 用于管理串行连接状态、轮询和重启功能
    - 在侧边栏添加串行状态指示灯，根据状态显示不同颜色和提示
    - 后端支持通过 REST API 获取状态和触发重启，并实现10秒无响应超时处理
    - 串行任务现在可通过信号强制重启，改善错误恢复流程
2026-02-12 feat(panel,wifi): 优化Wi-Fi状态显示与网络扫描逻辑
    优先根据网络测试结果显示绿色状态，而非仅检查连接状态
    在Wi-Fi管理器中显示已连接网络的IPv4地址
    修复nmcli扫描输出解析以正确处理SSID包含冒号的情况
    排序网络列表时优先显示已连接网络
2026-02-12 fix: wrong display of battery
    [battery.rs, imu_spi.rs, main.rs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]
2026-02-12 style: 统一代码格式并修复缩进问题
2026-02-12 fix(WifiManager): 修复未连接时 IP 地址显示条件
    调整状态判断逻辑，确保在已获取 IP 但未完全连接时仍能显示 IP 地址信息，并优化未获取 IP 时的占位文本显示。
2026-02-12 fix(WifiManager): 修复网络连接状态显示逻辑
    合并后端状态与扫描结果以准确判断活动连接
    优先使用后端状态，若未连接则检查扫描列表中的使用中网络
2026-02-12 fix: have a more rebust retry method
    [imu_spi.rs, main.rs]
2026-02-12 fix(linux/wifi): 修复获取已连接WiFi的IP地址的问题
2026-02-12 feat(serial): 增加串口通信的调试日志
    添加接收与发送数据的详细日志记录，包括数据包大小验证和反序列化结果，便于调试通信问题。
2026-02-12 feat(panel): 添加移动设备连接功能
    在侧边栏添加移动设备连接按钮，点击后显示包含 Wi-Fi 连接信息的二维码弹窗
    引入 qrcode.vue 库用于生成二维码，二维码内容包含当前 Wi-Fi 的 SSID 和 IP 地址
2026-02-12 fix: 修复WiFi连接时QR码中IP地址格式错误
    从WiFi状态中提取IP地址时，移除子网掩码部分，确保QR码只包含纯IP地址
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2026-02-12 feat(mobile): 重构通信协议为 WebSocket 并集成设备绑定
    - 移除蓝牙依赖，改用 WebSocket 连接下位机
    - 新增 WebSocket 服务、连接服务和消息协议定义
    - 实现设备绑定流程：扫码获取 IP 后通过 HTTP API 配置 WiFi
    - 更新控制、监控和设置 providers 以使用 WebSocket 发送指令和接收数据
    - 添加主题模式支持，改进 UI 组件的深色适配
    - 更新 iOS/Android 配置，移除蓝牙权限，添加网络权限
    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
2026-02-12 fix: 将串口握手超时从2秒增加至10秒
    避免因硬件响应较慢导致握手失败，提升连接稳定性
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2026-02-13 fix: trigger state change when receiving commands
    [battery.rs, main.rs, uart_rx.rs]
2026-06-09 backup: pre-reinstall 2026-06-09
    [powerfb.kicad_sch]
